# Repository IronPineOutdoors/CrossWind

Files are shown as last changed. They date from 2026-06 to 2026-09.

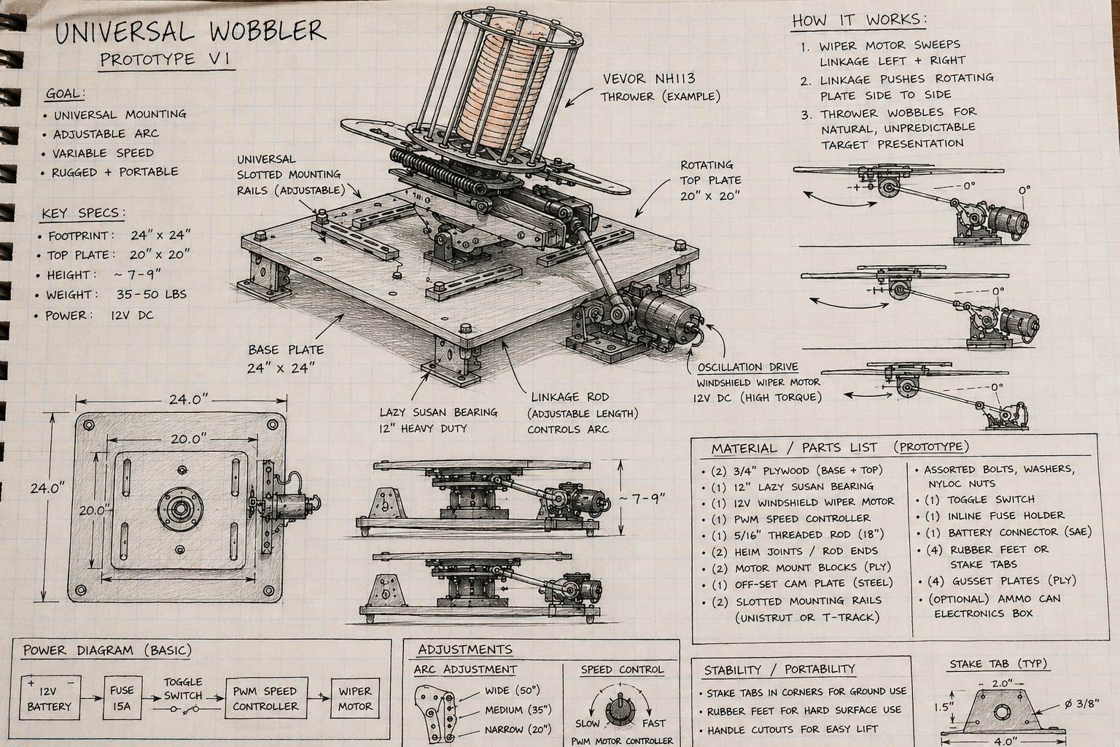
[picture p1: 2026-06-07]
mechanical/sketches/hand_drawn_concept_sketch_photo_style.png

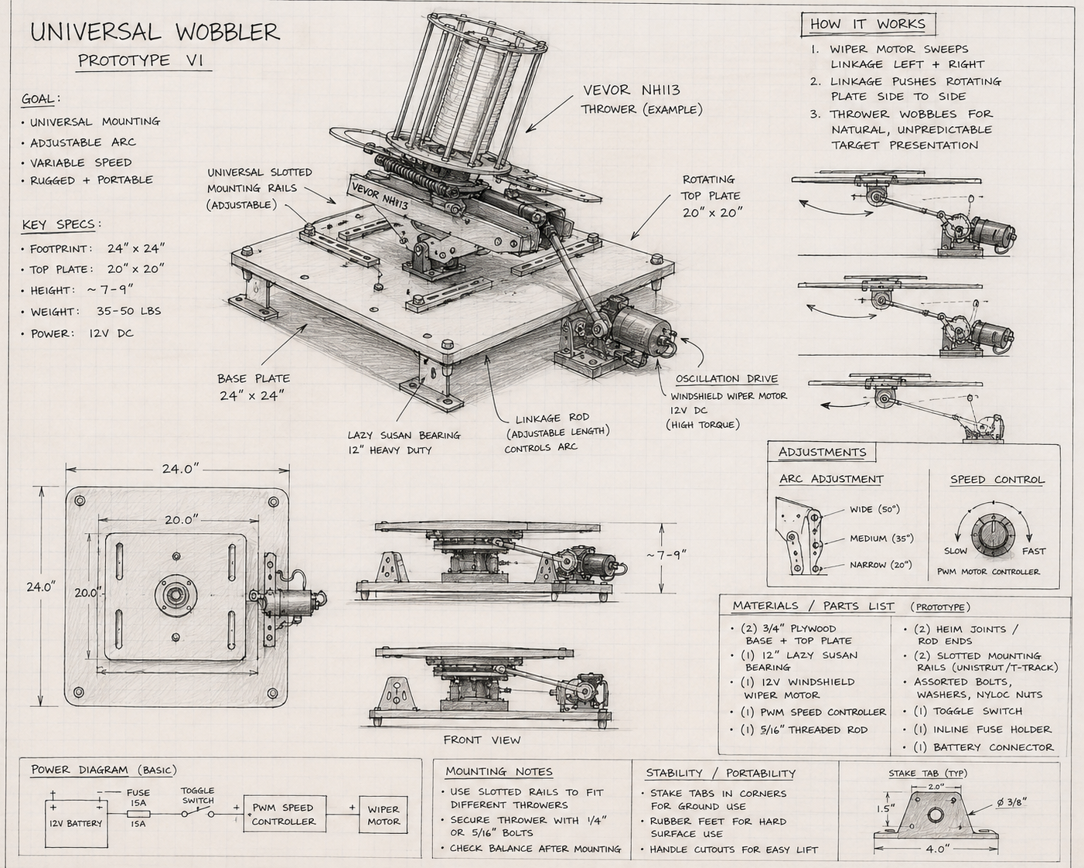
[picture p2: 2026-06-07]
mechanical/sketches/hand_drawn_concept_sketch.png

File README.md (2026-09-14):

# Crosswind

Crosswind is an Iron Pine Outdoors prototype for programmable target presentation: a universal wobbler base that can add controlled yaw, and later pitch, to automatic clay throwers.

Phase 1 is a single-axis yaw/sweep prototype. It uses a rotating thrower deck on a lazy susan bearing, a reversing wiper-motor linkage, a BTS7960 / IBT-2 motor driver, and two YL-99 roller limit modules that define the normal left/right travel boundaries and provide fault protection.

Phase 2 is planned as a dual-axis yaw + pitch system with programmable presentation modes.

ESP32 source identifies as `v1.12.0-rc.1`. Earlier Alpha bench results passed bounded motion and fault checks; the later motor-direction correction still needs physical verification. See [current status](docs/STATUS.md) for evidence and remaining integration work. The hardware below describes the Alpha design, not a completed assembly checklist.

## Current Phase

Phase 1: single-axis sweep prototype.

The first mechanical fitment target is a VEVOR NH113 thrower, but the base, rails, and mounting approach should remain adjustable so Crosswind can support other automatic throwers later.

## Phase 1 Hardware

- ESP32 dev board
- Legacy Arduino Uno/Nano fallback (not Alpha-equivalent)
- BTS7960 / IBT-2 motor driver
- 12V Mitsubishi Outlander rear wiper motor
- Left and right YL-99 limit switch modules
- Rotary encoder speed control with menu/select button
- Dedicated ARM and FIRE / TEST buttons
- Hosyond 2.42-inch 128x64 SSD1309 I2C OLED status display (ASIN B0G2RFLG1L) with the official five-conductor JST lid harness
- BME280 temperature, humidity, and pressure sensor on the shared I2C bus
- Dry-contact thrower trigger relay
- DIYables common-cathode RGB status LED
- 20V/24V tool battery input
- High-current buck converter for 12V bus
- Fused 5V buck converter for controller/support electronics
- Waterproof electronics box
- 28" x 28" 3/4" plywood base
- 20" x 20" rotating thrower deck
- 12" lazy susan bearing

## Folder Structure

- `firmware/crosswind-esp32/` - PlatformIO ESP32 firmware split into motor, limits, inputs, modes, storage, BLE, environment, display, RGB status LED, trigger, and diagnostics modules.
- `firmware/crosswind-arduino/` - Arduino Uno/Nano fallback firmware.
- `mechanical/` - Phase 1 and Phase 2 mechanical notes, dimensions, fitment, and cut lists.
- `electrical/` - Pinout, power system, fusing, the [five-pin OLED lid-harness standard](electrical/oled-lid-harness.md), the [Deutsch DT 6-pin limit-switch harness standard](electrical/limit-switch-harness.md), and wiring checklist.
- `cad/` - CAD export/drop folders for Phase 1 and Phase 2.
- `testing/` - Bench, motor, sweep, runtime, and field test records.
- `branding/` - Iron Pine Outdoors and Crosswind product identity notes.
- `docs/` - Requirements, build plans, safety notes, changelog, and roadmap.

## Quick Start

1. Read `docs/safety-notes.md`.
2. Review `electrical/pinout.md` before wiring.
3. Build the Phase 1 base from `mechanical/phase-1/dimensions.md` and `mechanical/phase-1/cut-list.md`.
4. Flash the ESP32 firmware from `firmware/crosswind-esp32/`.
5. Run `testing/bench-test-checklist.md` with the thrower removed.
6. Mount the thrower only after switch, motor, and fault behavior are verified.

## Safety Warning

Crosswind moves heavy equipment with a 12V motor. Keep hands clear of linkages, rotating plates, pinch points, and the thrower arm path. Use fuses, a shared ground, strain relief, and a reachable power disconnect. Bench test without the thrower mounted before any live thrower test.

## Project Context

- [Current status](docs/STATUS.md): implemented behavior, physical evidence and open questions.
- [Roadmap](docs/roadmap.md): next engineering milestones.
- [Engineering decisions](docs/DECISIONS.md): durable choices and rationale.
- [Codex working guide](AGENTS.md): repository operating instructions.
- [Documentation index](docs/README.md): requirements, build plans, safety and history.

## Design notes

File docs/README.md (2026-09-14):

# Docs

Start with [CrossWind overview](../README.md), then use:

- [STATUS](STATUS.md): current implementation, test evidence and uncertainty.
- [Roadmap](roadmap.md): future work.
- [DECISIONS](DECISIONS.md): important choices and why.
- [AGENTS](../AGENTS.md): how Codex should work in this repository.
- [Product requirements](product-requirements.md): intended capabilities and constraints.
- [Phase 1 build plan](build-plan-phase-1.md) and [Phase 2 build plan](build-plan-phase-2.md): construction plans, not completion records.
- [Safety notes](safety-notes.md): required precautions.
- [Changelog](changelog.md): historical changes.

Detailed implementation belongs with its subsystem:

- [Pinout](../electrical/pinout.md) and [wiring checklist](../electrical/wiring-checklist.md).
- [OLED lid harness](../electrical/oled-lid-harness.md) and [limit harness](../electrical/limit-switch-harness.md).
- [Wiper linkage](../mechanical/phase-1/linkage-notes.md) and [limit layout](../mechanical/phase-1/limit-switch-layout.md).
- [ESP32 firmware](../firmware/crosswind-esp32/README.md), [CAD](../cad/phase-1/README.md) and [test records](../testing/README.md).

Existing nested electrical/mechanical aliases are retained for compatibility; update the canonical subsystem files rather than duplicating detail here.

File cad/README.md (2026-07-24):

# CAD

Store CAD exports and source files here once the physical prototype dimensions settle.

Keep exported PDFs or STEP files alongside native CAD files so collaborators can view designs without the original CAD tool.

Alpha controller-lid CAD must account for the verified 2.42-inch SSD1309 OLED and its official five-conductor, five-position JST harness. See `phase-1/README.md` and `../electrical/oled-lid-harness.md`; use measurements from installed hardware rather than generic display or JST dimensions.

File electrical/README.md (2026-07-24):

# Electrical

This folder documents Crosswind wiring, power distribution, and safety checks.

Use these notes before powering the controller or motor driver.

The finalized limit-switch cable colors, Deutsch DT 6-pin pinout, diagrams, and assembly procedure are in [limit-switch-harness.md](limit-switch-harness.md).

The official Crosswind Alpha OLED connector pinout, five-conductor lid-harness diagram, BOM, fabrication procedure, and acceptance tests are in [oled-lid-harness.md](oled-lid-harness.md).

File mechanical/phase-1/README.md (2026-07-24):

# Mechanical Phase 1

Phase 1 is a single-axis yaw/sweep base.

Core dimensions:

- 28" x 28" fixed plywood base
- 20" x 20" rotating top plate
- 12" lazy susan bearing
- Off-center crank-driven wiper motor mounted to the stationary base plate
- Linkage to the rear corner or tab of the rotating top plate
- Adjustable safety flags/tabs on the rotating plate
- Left/right roller switches on adjustable stationary brackets

The top plate rides on the lazy susan bearing. The wiper motor should mount to the stationary base plate with its output crank offset from the rotation center; the linkage does not need to attach at the exact center of the rotating top plate. Mount the BTS7960 with its heatsink exposed and ventilated inside the electronics enclosure.

See `limit-switch-layout.md` for the Phase 1 YL-99 safety switch layout.

## Controller Display

The controller enclosure now uses a Hosyond 2.42-inch 128x64 SSD1309 OLED. The logical resolution is unchanged, but the larger physical module may require revisions to the panel opening, mounting-hole locations, standoffs, and display bezel.

The enclosure lid must accommodate the official five-conductor OLED harness and five-position JST connector, including strain relief and a service loop. See [OLED Lid Harness Standard](../../electrical/oled-lid-harness.md).

TODO: measure the actual installed OLED module and update the enclosure/CAD dimensions. Do not infer board or mounting dimensions from the 2.42-inch diagonal specification.

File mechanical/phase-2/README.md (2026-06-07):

# Mechanical Phase 2

Phase 2 adds pitch control to the yaw base.

The likely direction is a tilt cradle or adjustable subframe driven by a 12V linear actuator.

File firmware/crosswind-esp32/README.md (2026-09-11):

# Crosswind ESP32 Firmware

Current release candidate: `v1.12.0-rc.1`. The Alpha bounded-motion behavior has been compiled and bench-validated with the installed motor and both YL-99 endpoints.

This folder contains the Phase 1 ESP32 controller firmware in a PlatformIO project.

Current PlatformIO settings:

- Board: `esp32dev`
- Framework: Arduino
- Upload port: `COM3`
- Monitor port: `COM3`
- Monitor speed: `115200`

The code is split into beginner-readable modules:

- `config.h` - pin assignments, constants, shared enums, and the main controller state.
- `motor.*` - BTS7960 / IBT-2 motor control, safe reversal, soft-start ramping, and stop behavior.
- `limits.*` - left/right roller switch reads and debounce.
- `inputs.*` - ARM/FIRE buttons, rotary encoder speed/menu input, and optional speed potentiometer reads.
- `modes.*` - bounded single-axis sweep/reversal and timed centering, with future hooks for the second axis.
- `storage.*` - Preferences-backed mode, last fault, and last speed storage.
- `ble_control.*` - optional BLE command interface.
- `environment.*` - BME280 temperature, humidity, and pressure support.
- `display.*` - U8g2-driven SSD1309 128x64 OLED status display with I2C diagnostics and recovery.
- `status_led.*` - non-blocking DIYables RGB status LED control.
- `trigger.*` - non-blocking thrower relay pulse control.
- `diagnostics.*` - Serial startup diagnostics and runtime status payloads.

## Phase 1 Behavior

Default mode is `SWEEP`. The motor travels between the left and right limit switches, stops at each end, observes direction-change dead time, and reverses. `RANDOM` and `FLUSH` use the same bounded single-axis movement until the second axis and mode-specific motion are added. `CENTERING` establishes both endpoints, measures end-to-end travel time, returns for half that time, and stops.

`MOTOR_DIRECTION_INVERTED = true` corrects the installed motor's reported reverse
travel: logical RIGHT now drives LPWM, and logical LEFT drives RPWM. Direction
names mean plate travel toward the corresponding physical limit, viewed from one
consistent operator position, not shaft rotation viewed from underneath. Limit
wiring remains Left/Green/GPIO34 and Right/Blue/GPIO35. Startup logs the inversion
setting; output diagnostics continue to name the actual RPWM/LPWM terminals.
Do not also swap motor leads when applying this correction, which would reverse
it again. After flashing, first verify direction with unloaded motion away from
endpoints and accessible power cutoff, then verify each actual endpoint causes
reversal away and releases normally. Physical verification remains required.

The Alpha limit switches are normal travel boundaries as well as safety inputs. A single active limit commands movement away from that end; the switch must release within `LIMIT_DWELL_MS`. Both limits active together, failure to release, or failure to reach an endpoint within `MAX_TRAVEL_TIME_MS` latches a fault and stops the motor. A single active limit at startup is valid and establishes the initial direction away from that endpoint.

The controller permits motor START with one limit active because the mode controller selects the direction away from it. ARM and FIRE remain blocked while either limit is active, and a limit transition while armed returns the controller to SAFE. The powered limit modules provide defined HIGH outputs when released and LOW outputs when pressed; limit monitoring and fault protection are enabled. Stored settings are sanity-checked on boot, and BLE speed commands must be numeric values from `0` to `255`.

An E-stop input path exists as a disabled placeholder with `ESTOP_PIN = -1`. Assigning that pin in `config.h` enables a pulled-to-ground emergency stop input that latches `FAULT: ESTOP`. BLE command writes are rate-limited by `BLE_COMMAND_MIN_INTERVAL_MS`.

Motor session timeout and motor overcurrent fault hooks exist but are disabled by default. They require configuring `ENABLE_MOTOR_SESSION_TIMEOUT` or `ENABLE_MOTOR_OVERCURRENT_FAULT` plus the related timeout/current-sense constants in `config.h`.

The Alpha bench controller uses the rotary encoder for speed and local menu control, a dedicated ARM button on GPIO16, and a dedicated FIRE / TEST button on GPIO17. Press the encoder to open the menu, rotate to navigate, and press to select. The menu contains Motor, Mode, Environment, Diagnostics, and About pages. Motor speed has an explicit edit mode; direction and operating-mode changes require the motor to be stopped. Live environment, limit, fault, and relay information is available from the read-only status pages. Select `< Back` to return or `Exit` to close the menu. Any latched fault closes the menu so safety status takes priority. Menu motor control uses the same enabled fault, limit, E-stop, and temperature protections as BLE. The relay can only fire when `systemArmed` is true and no fault is active. The encoder button never triggers the relay.

On boot the system always starts `SAFE` / unarmed and the relay is initialized off. Pressing ARM toggles `ARM ON` / `ARM OFF` in Serial and updates the OLED. Pressing FIRE while safe prints `FIRE BLOCKED - NOT ARMED`; pressing FIRE while armed pulses the relay using the existing non-blocking trigger timing.

The verified Hosyond 2.42-inch 128x64 SSD1309 OLED uses U8g2 and the official five-conductor JST lid harness: GND, 3.3 V, GPIO21 SDA, GPIO22 SCL, and GPIO5 RESET. It retains the existing home-screen layout: motor speed percentage, `SAFE`, `ARMED`, `FAULT`, `WARNING`, or `FIRING`, relay `ON`/`OFF`, and `Limit: OK`, `ACTIVE`, `FAULT: LIMIT`, or `FAULT: BOTH`. At startup it briefly shows an animated Crosswind rotor, moving wind streaks, and a system-start progress bar before transitioning to the home screen. The RGB status LED mirrors the same safety state with green ready, blue armed, red fault, yellow warning/hot, and a white/purple firing flash.

## Build

Install PlatformIO, then run:

```sh
pio run
```

Upload with:

```sh
pio run --target upload
```

GitHub Actions also builds this PlatformIO project on pushes and pull requests that touch `firmware/crosswind-esp32/`.

## BLE Commands

- `START`
- `STOP`
- `MODE=SWEEP`
- `MODE=RANDOM`
- `MODE=FLUSH`
- `MODE=CENTERING`
- `SPEED=0-255`
- `STATUS`
- `CLEAR_FAULT`
- `TRIGGER`
- `FIRE`
- `LAUNCH`

Trigger commands and the FIRE / TEST button pulse the thrower relay only when the system is armed. They are ignored while faulted. The relay pulse remains non-blocking and uses `TRIGGER_PULSE_MS`.

Limit faults can be cleared from BLE with `CLEAR_FAULT`, or locally with the ARM/encoder button, only after both limit switches read clear.

Modes accepted by BLE are `SWEEP`, `RANDOM`, `FLUSH`, and `CENTERING`. `SWEEP`, `RANDOM`, and `FLUSH` currently share bounded end-to-end movement. `CENTERING` measures a complete traverse and returns halfway before stopping. Automatic triggering remains disabled unless `ENABLE_AUTOMATIC_TRIGGER` is intentionally enabled and safety-tested.

## Current Alpha Pinout

| Function | ESP32 GPIO |
| --- | ---: |
| BTS7960 RPWM | 18 |
| BTS7960 LPWM | 19 |
| BTS7960 R_EN | 23 |
| BTS7960 L_EN | 13 |
| Thrower relay input | 14 |
| ARM button | 16 |
| FIRE / TEST button | 17 |
| Rotary encoder CLK | 32 |
| Rotary encoder DT | 33 |
| Rotary encoder SW | 25 |
| Left limit | 34 |
| Right limit | 35 |
| OLED SDA | 21 |
| OLED SCL | 22 |
| OLED RES | 5 |
| BME280 SDA | 21 |
| BME280 SCL | 22 |
| RGB LED red | 27 |
| RGB LED green | 12 |
| RGB LED blue | 4 |
| Potentiometer placeholder | 39 |
| E-stop placeholder | disabled |
| Motor current sense placeholder | disabled |

The DIYables RGB LED module is common cathode with built-in resistors: connect module `GND` to common ground, `R` to GPIO27, `G` to GPIO12, and `B` to GPIO4. GPIO12 is a boot strapping pin on many ESP32 boards. Keep it for the Alpha wiring above; GPIO5 is reserved for OLED reset and is not available as an RGB fallback.

The electrical source of truth for display connector numbering, harness fabrication, and acceptance testing is [OLED Lid Harness Standard](../../electrical/oled-lid-harness.md).

## Environmental Sensor

Alpha firmware reads a BME280 on the existing OLED I2C bus at GPIO21/GPIO22 no faster than once every 2 seconds by default. It tries address `0x76` first and then `0x77`, stores the last valid temperature, humidity, and pressure reading, and reports `ENV ERR` if a read fails. `HOT` appears at `TEMP_WARNING_F`; `TEMP FAULT` stops the motor when `ENABLE_TEMP_FAULTS` is true and temperature reaches `TEMP_FAULT_F`. The Serial/BLE status payload includes `pressureHpa`.

## Quick Test Checklist

See `firmware-test-checklist.md` for a fuller bench checklist and `fault-matrix.md` for fault behavior.

1. Upload firmware with PlatformIO.
2. Confirm Serial reports the I2C scan and SSD1309 address, then confirm the OLED startup test transitions to the home screen.
3. Confirm encoder rotation changes motor speed.
4. Confirm ARM toggles between `SAFE` and `ARMED`.
5. Confirm FIRE is blocked while `SAFE`.
6. Confirm FIRE activates the relay only while `ARMED`.
7. Confirm relay `COM`/`NO` act as dry-contact continuity only.
8. Confirm left/right limits show inactive and active correctly in Serial/OLED setup view.
9. Confirm motor PWM changes speed on the bench before connecting linkage.
10. Confirm a normal endpoint reverses motion, while both limits, a stuck limit, travel timeout, or temperature fault stops motor output and blocks triggering.

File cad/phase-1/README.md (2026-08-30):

# CAD Phase 1

Use this folder for the yaw base, top plate, switch brackets, motor mount, and electronics box layout.

Printable adjustable YL-99 switch holders are in [`limit-switch-holder`](limit-switch-holder/README.md).
Matching printable striker flags are in [`limit-switch-flag`](limit-switch-flag/README.md).

## Controller Lid

The official Alpha controller lid uses the Hosyond 2.42-inch 128x64 SSD1309 OLED and its five-conductor JST harness: GND, 3.3 V, SDA, SCL, and GPIO5 RESET. Future enclosure and wiring-layout CAD must reserve routing, bend clearance, strain relief, and service-loop space for all five conductors and the five-position connector.

The current measured side-panel layout is recorded in [side-panel-layout.md](side-panel-layout.md). The OLED module and primary control locations are measured; dimensions explicitly marked for verification must not be treated as fabrication-ready.

A provisional printable fit-check panel, including four corner M3 mounting holes, is in [`side-panel`](side-panel/README.md).

The matching provisional 30-degree open-back body is in [`control-pod`](control-pod/README.md). A wide bolt-through foot intended to be printed four times is in [`base-foot`](base-foot/README.md).

TODO: measure the JST housing, visible OLED window, standoffs, bezel overlap, cable bend radius, service loop, RGB LED lens/body/PCB, and BME280 board envelope before producing a final dimensional drawing. Do not infer missing dimensions from a generic part name.

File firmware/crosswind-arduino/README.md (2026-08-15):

# Crosswind Arduino AVR Firmware

This folder contains the Arduino Uno/Nano Phase 1 fallback firmware.

Open `Crosswind_Controller/Crosswind_Controller.ino` in the Arduino IDE, select an Uno or Nano board, and upload.

The AVR firmware is a legacy fallback and does not yet mirror the hardware-validated `v1.12.0-rc.1` ESP32 bounded-motion state machine:

- Default mode is `SWEEP`.
- The BTS7960 outputs are handled so both directions are never energized at once.
- Direction changes zero both PWM channels before reversing.
- Limit switches default to normally closed wiring with configurable active state.
- EEPROM stores only mode, last fault, and last speed.

Do not use this fallback for the current Alpha release candidate without separately reviewing and porting endpoint reversal, stuck-limit timeout, travel timeout, and timed centering. The ESP32 firmware is the validated controller for Alpha.

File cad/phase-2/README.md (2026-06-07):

# CAD Phase 2

Use this folder for pitch cradle, actuator mounts, and dual-axis packaging work.

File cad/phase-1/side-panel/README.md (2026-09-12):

# Alpha Side Panel Print

`crosswind_alpha_side_panel.stl` is a provisional, flat-print prototype for checking the OLED and control layout. Print it flat on the bed; supports are not required.

## Current geometry

- Panel: 150 x 100 x 3 mm
- Four panel mounting holes: 3.2 mm diameter (M3 clearance), centers 5 mm from each corner
- OLED visible opening: 57 x 28 mm, shifted 2.75 mm upward from the PCB center
- Four OLED PCB holes: 3.2 mm diameter; horizontal span includes the measured fit correction (left pair 1 mm outward and right pair 1 mm outward)
- ARM and FIRE openings: 16.5 mm diameter, 70 mm center-to-center
- Recessed `ARM` and `FIRE` labels above their respective buttons
- Encoder opening: 8 mm diameter for the threaded bushing, with recessed `SPEED` and `-` / `+` direction markings
- RGB LED opening: provisional 5.2 mm diameter, lowered 11 mm below the OLED for vertical PCB clearance
- Paired 10 mm-tall, 3 mm-thick rear anti-rotation rails around the encoder and RGB LED modules
- Upper-right recessed wordmark: `CROSSWIND` / `BY IRON PINE OUTDOORS`, 0.6 mm deep

The encoder rails provisionally fit an 18 mm-wide PCB and the LED rails a 15 mm-wide PCB, each with 0.4 mm total clearance. Fit-print photos showed that the original 3 mm rails ended below both elevated PCBs; the revised rails rise 10 mm from the rear panel surface and are 3 mm thick so they reach the board edges. They resist rotation but do not replace the components' panel nuts or other retention hardware. The STL is oriented with the exterior/engraved face at Z=0 and the rear rails rising upward, so its default orientation prints without supports. The complete part is mirrored for face-down printing: lettering appears reversed from the tab side in the slicer and reads normally on the finished exterior. Keep the rail contact surfaces clear of solder joints and wiring.

The panel size, OLED window placement, button vertical datum, LED diameter, module widths, and interpretation of the reported OLED mounting-hole spans are provisional. Use this print as a fit coupon/prototype, not as the final weather-sealed panel.

The BME280 mounting tab is intentionally omitted until its PCB envelope, hole coordinates, connector orientation, airflow clearance, and desired location are measured. Those details determine whether the tab belongs on the rear face or panel edge.

A master-power toggle location is not cut yet. Record its panel-bushing or rectangular cutout dimensions, anti-rotation feature, rear body envelope, terminal clearance, and DC voltage/current rating before adding it to the printable panel.

The engraved lockup uses a dependency-free block alphabet sized for FDM printing. For the cleanest lettering, print the exterior face upward at 0.2 mm layers or finer. A contrasting paint fill can be wiped into the recess after printing.

## Regeneration

Install the generator dependency and run:

```powershell
python -m pip install manifold3d
python .\generate_stl.py
```

Edit the constants at the top of `generate_stl.py` when measured dimensions replace the provisional assumptions.

## OLED window fit correction ? 2026-09-12

The installed photo showed the top text clipped and an extra gap below the OLED,
measured by the user at approximately 2.7-2.75 mm. The viewing opening moves
2.75 mm toward the panel top without changing its 57 x 28 mm size. All OLED and
panel mounting holes, control cutouts, and rear rails retain their positions.
The window now spans Y=52.25 to 80.25 mm from the panel bottom (previously
49.5 to 77.5 mm). Reprint the faceplate and check that the top line and bottom
pixel row are visible; this approximate fit correction still needs physical
verification. The existing pod and OLED mounting pattern are reused.

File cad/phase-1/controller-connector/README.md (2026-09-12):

# Controller connector: measured housings and fit gauges

User's existing Alpha controller harness has two six-position joined connections
and one four-position joined connection, each using a middle pin header. Thirteen
positions are used and three reserved. Preserve the existing wire assignments;
this is not a new IPC-101 pinout or a change to its separate STOP interface.

Kit: ELEAD B0G2L3LGWD, marketed as XH-style/Dupont assortment. Do not infer genuine
JST dimensional compatibility or wire-to-wire contact engagement from the title.

## Measurements received 2026-09-11

| Feature | mm | Evidence / interpretation |
| --- | ---: | --- |
| Six-position housing width | 15.97 | Explicitly confirmed by user, photo 184505 |
| Housing depth | 7.91 | Photo 185052; interpreted as mating-axis body depth |
| Six-position housing thickness | 3.98 | Photo 185114 |
| Header feature | 5.53 | Photo 185130; not used as assembled-pair length |
| Four-position housing width | 10.65 | Photo 185203 |
| Four-position housing thickness | 3.85 | Photo 185220 |
| Lip feature | 0.77 | Photo 185248; precise contact faces not established, not used yet |
| Rib inset from each housing end | 2.51 | User confirmed nearest edge; both connector sizes, wire side |
| Rib width | 0.71 | User confirmed; two ribs per housing |
| Maximum hooked-tip width | 1.28 | User confirmed 2026-09-12 after all three gauges caught |
| Rib projection from flat body | 0.79 | User confirmed after first fit print |

The original loose middle-header arrangement below is historical. The selected
IPC-101 carrier now uses matching PCB headers; see the confirmed mating update
at the end of this document. These gauges establish cable-body clearance only.

## Revised print: hooked-rib clearance (2026-09-12)

The first rectangular apertures caught on the two underside ribs. Regenerated
STLs now include two through-notches per opening, on the edge away from the
raised identification dots. Orient the connector ribs toward those notches.
The filenames replace the original rectangular gauges; reload the revised STL
and slice again rather than reusing the previous print job.

All three previous gauges failed to align in the physical fit check. The new
close-up shows angled ribs with wider hooked tips; the user measured the maximum
tip width as 1.28 mm, versus the 0.71 mm shaft used previously.

Rib locations retain the measured 2.51 mm shaft inset. Because the lateral tip
offset and rib angle are unmeasured, this diagnostic revision allows the extra
0.57 mm on BOTH sides of each shaft, making a 1.85 mm swept envelope before
clearance. This is a conservative test allowance, not a measured hook profile.
Notch widths are now 2.05, 2.25, and 2.45 mm for one, two, and three dots.
The same allowance is provisionally used for both housing sizes; verify each.
Each notch still extends 0.79 mm beyond the rectangular aperture edge, preserving
the same per-side clearance at the rib tip as at the flat body. Hook projection
has not been remeasured. The main rectangular openings are unchanged.
Reload and reslice the regenerated STLs; dot counts and filenames are unchanged.

Print `Connector_Fit_All_Three_PRINT.stl` on the A1 in PETG, 0.4 mm nozzle,
0.2 mm layers, four walls, solid fill; flat as exported, no supports. Individual
STLs are provided if only one clearance needs repeating. The three gauges are
38 x 16 x 2 mm plus raised identification dots; the combined print is 38 x 58 mm.

Each gauge has a wide six-position opening and a narrower four-position opening.
The added clearance is TOTAL, so 0.4 mm means 0.2 mm per side for a centered part.

| Raised dots | Total added clearance | Six-position opening | Four-position opening |
| ---: | ---: | --- | --- |
| 1 | 0.2 mm | 16.17 x 4.18 mm | 10.85 x 4.05 mm |
| 2 | 0.4 mm | 16.37 x 4.38 mm | 11.05 x 4.25 mm |
| 3 | 0.6 mm | 16.57 x 4.58 mm | 11.25 x 4.45 mm |

With power removed, test loose housings by inserting the body gently into its
opening. Do not force a flange/latch through an opening intended for the body;
note whether it is the body or an external ridge that stops insertion. Remove
first-layer burrs before judging fit. Report the smallest gauge that slides
without force for EACH connector size. These are dimensional coupons, not
electrical housings, clamps or strain relief.

## Confirmed fit selections (2026-09-12)

Use these separate clearances for subsequent carrier design, retaining the
revised hooked-rib relief geometry:

| Housing | Selected gauge | Total clearance | Main opening | Rib-notch width |
| --- | --- | ---: | --- | ---: |
| Six-position | 2-dot | 0.4 mm | 16.37 x 4.38 mm | 2.25 mm |
| Four-position | 3-dot | 0.6 mm | 11.25 x 4.45 mm | 2.45 mm |

User reported the revised 1-dot was still close on the six-position housing and
the four-position housing did not pass through. The revised 2-dot fit the
six-position housing well, but the four-position housing required force.
Possible hook damage on that forced sample was not confirmed. The user then
checked a fresh four-position housing directly in the revised 3-dot and confirmed
that they liked its fit; the four-position selection is based on that fresh
sample. Existing comparison-gauge STLs remain unchanged.

These results establish aperture fit only; joined-pair engagement and carrier
retention remain to be established.

## Remaining design inputs

- Fixed PCB-header dimensions, tail geometry, pin spacing/offset and fully mated
  envelope for both sizes; the loose middle-header concept is superseded.
- Final retention must leave the metal contacts fully engaged without pushing
  pins backward or relying on the wires for structural support.
- USB service port remains a separate pending task: ESP socket type, mounting
  location and chosen extension cable geometry have not yet been confirmed.

`generate_fit_gauges.py` verifies clear apertures, manifold status, watertightness,
consistent winding, positive volume and the expected number of separate solids.
Physical dimensions and connector retention require printed fit verification.

## IPC-101 development direction (2026-09-12)

The user selected IPC-101 for Alpha and future IPC-100. The new carrier plan uses
one accepted six-position OLED opening and one accepted four-position controls
opening, with STOP separate. The earlier 6+6+4 description records the existing
Alpha harness, not the new panel allocation. See the
[IPC-101 adapter specification](../../../electrical/ipc101-adapter-plan.md) for
circuit assignments, firmware gaps, GPIO savings and remaining mechanical inputs.

## Confirmed PCB-header mating (2026-09-12)

User confirmed both cable housings connect to the kit's matching shrouded PCB
headers and hold via their hooks (assembled-pair photo 20260912_100515.jpg).
Develop the fixed side around these headers on a supported adapter PCB. Preserve
hook engagement and release access. Existing gauge fits remain cable-clearance
references, not dimensions for mounting the larger header bodies. Electrical
continuity and header/PCB dimensions remain unverified.

## PCB-header test prints

New fixed-header body and solder-tail coupons are ready in
`PCB_Header_All_Tests_PRINT.stl`. Follow
[PCB header test instructions](PCB_Header_Test_Instructions.md); these use
provisional photo-derived shroud sizes and do not replace the accepted cable
housing gauges.

### Header fit feedback and refinement

On 2026-09-12 the user corrected the solder-tail selection to TWO dots (1.1 mm
square holes); ONE dot (0.9 mm) was too tight. Original one-dot
body openings were closest but still slightly oversized. New body-only tests:
`PCB_Header_Refine_All_PRINT.stl`, with a raised bar distinguishing this series.
See the refinement table in the test instructions. Original files are preserved.

### Four-pin outer-edge adjustment

Refinement three-dot was preferred, with the four-pin outer side still slightly
snug and causing a subtle angle. `PCB_Header_Outer_Relief_All_PRINT.stl` tests
0.2 / 0.4 mm relief at only the four-pin outboard short edge. Two raised bars
identify this series; see the test instructions. Six-pin remains 18 x 7 mm.

## Fit clarification: raised identification dots (2026-09-12)

User subsequently attributed the apparent four-pin tilt to the raised coupon
dots preventing the plates from sitting flush together, and believes the fit is
OK. Retain refinement THREE-dot body openings: six-pin 18.0 x 7.0 mm and four-pin
13.0 x 7.0 mm. Retain original TWO-dot tail holes: 1.1 mm square at provisional
2.50 mm pitch. The outer-edge-relief coupons are superseded diagnostic options;
do not carry their enlargement into the carrier. Final mating/support surfaces
must be flat, with identification outside those surfaces. Integrated header
seating and mating still need an assembly fit check.

## Next assembled fit print

`PCB_Header_Assembly_All_PRINT.stl` contains a flat guide, sliding pin plate and
open stand. Follow [assembly instructions](PCB_Header_Assembly_Instructions.md).
This combines the accepted body and pin fits without raised dots interfering
with seating. It is a hand-held alignment test, not a retained final connector.

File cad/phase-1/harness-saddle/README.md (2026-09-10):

# Harness saddle for 13.8 mm automotive loom

First-fit prototype for tubing measured at 13.8 mm outside diameter. Install over
an existing harness with the open side against the wooden mounting surface.

- Installed envelope: 42 x 18 x 17 mm.
- Smooth channel: 14.2 mm wide, 13.8 mm high above the mounting surface.
- Arch wall: 3.2 mm; mounting ears: 4 mm thick.
- Two 4.6 mm clearance holes, 30 mm center to center, for #6 or #8 screws.
- Flat screw seats accept pan heads; small flat washers can spread the load.
  Use washers no larger than 9 mm OD to retain clearance to the arch.

## Bambu A1 printing

Open `Crosswind_Harness_Saddle_13.8mm_PRINT.stl` in Bambu Studio and select your
A1 and actual filament profile. The STL is already resting on its flat end face:
the print is 18 mm tall and the arch lies in the layer plane. Do not auto-orient
it onto the mounting ears. Use PETG, a 0.4 mm nozzle, 0.2 mm layers, five walls,
five top/bottom layers, and 35% gyroid infill. Supports are not intended; the
horizontal 4.6 mm screw bores have short bridges. Deburr/check screw passage.
Use a 3 mm outer brim if adhesion requires it. Print one for fit before making more.

## Mounting and grip

For 3/4-inch plywood use two #6 or #8 x 3/4-inch pan-head WOOD screws.
Machine screws require nuts or threaded inserts. The 4 mm ears leave at most
15.05 mm of screw penetration before adding washers, below 19.05 mm plywood
thickness. Verify the actual wood thickness and bearing clearance first.
Pilot drill to suit the wood and screw root diameter; limit drill depth.
Snug the ears against the wood without crushing the print or tubing.

This is a loom hold-down, with strain relief dependent on actual friction and
loom stiffness. Corrugation pitch and groove diameter were not supplied, so
there are no groove-locking teeth. The channel has lateral clearance and nominal
contact at its crown; it does not guarantee axial retention. With power off,
check whether the loom slides under the expected pull. A thin rubber strip may
improve grip if it fits without forcing the ears down or crushing the loom.
Wires may slide independently inside split loom: retain the harness separately
where connector strain relief is required. Leave a service loop at moving joints.

`generate_stl.py` recreates the STL and preview and checks one connected,
watertight, consistently wound solid, positive volume, and bounding dimensions.
Mesh checks do not establish physical fit or pull strength.

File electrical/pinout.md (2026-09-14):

# Pinout

## ESP32 Pins

| Function | ESP32 Pin | Notes |
| --- | --- | --- |
| BTS7960 RPWM | GPIO18 | RPWM terminal; logical LEFT with current inverted mapping |
| BTS7960 LPWM | GPIO19 | LPWM terminal; logical RIGHT with current inverted mapping |
| BTS7960 R_EN | GPIO23 | Right enable |
| BTS7960 L_EN | GPIO13 | Left enable |
| SSD1309 OLED SDA | GPIO21 | Shared I2C bus |
| SSD1309 OLED SCL | GPIO22 | Shared I2C bus |
| SSD1309 OLED RES | GPIO5 | Active-LOW hardware reset for five-pin module |
| BME280 SDA | GPIO21 | Optional environment sensor on shared I2C bus |
| BME280 SCL | GPIO22 | Optional environment sensor on shared I2C bus |
| Left limit | GPIO34 | Green, DT pin 1; powered module OUT, active LOW; module onboard pull-up |
| Right limit | GPIO35 | Blue, DT pin 2; powered module OUT, active LOW; module onboard pull-up |
| ARM button | GPIO16 | Button to GND, `INPUT_PULLUP`, pressed LOW |
| FIRE / TEST button | GPIO17 | Button to GND, `INPUT_PULLUP`, pressed LOW |
| Speed potentiometer | GPIO39 | 0-3.3V analog input |
| Rotary encoder CLK | GPIO32 | Active speed input in current ESP32 build |
| Rotary encoder DT | GPIO33 | Active speed input in current ESP32 build |
| Rotary encoder SW | GPIO25 | Menu/select button |
| Thrower trigger relay | GPIO14 | Relay input only; relay contacts are dry contact across pedal wires |
| RGB LED red | GPIO27 | DIYables common cathode RGB module R input, PWM |
| RGB LED green | GPIO12 | DIYables common cathode RGB module G input, PWM |
| RGB LED blue | GPIO4 | DIYables common cathode RGB module B input, PWM |

## BTS7960 Pins

- `B+` and `B-` connect to the fused 12V bus from the high-current buck converter.
- `M+` and `M-` connect to the wiper motor.
- `RPWM`, `LPWM`, `R_EN`, and `L_EN` connect to the ESP32 pins above.
- ESP32 ground, BTS7960 logic ground, buck ground, and battery negative must be common.

## Limit Switches

Use the [finalized limit-switch harness standard](limit-switch-harness.md): Green / DT pin 1 is Left OUT, Blue / pin 2 is Right OUT, White / pin 3 is Lower OUT, Yellow / pin 4 is Upper OUT, Black / pin 5 is shared ground, and Red / pin 6 is regulated 3.3 V. The powered modules output HIGH normally and short OUT to ground when pressed, so active is LOW.

During Alpha, Green, Blue, Black, and Red are connected. White and Yellow remain terminated but unused. GPIO34/GPIO35 do not support internal pull-ups, so Alpha relies on the powered modules' onboard pull-ups. A broken or disconnected OUT wire leaves the input undefined and is not automatically detected. These switches command normal reversal and provide safety input, but separate physical hard stops remain required.

## RGB Status LED

The DIYables RGB LED module is common cathode with built-in resistors. Connect module `GND` to common ground, `R` to GPIO27, `G` to GPIO12, and `B` to GPIO4. Because common cathode colors turn on when driven HIGH, PWM values above 0 illuminate the color and PWM 0 turns it off.

GPIO12 can affect boot mode on some ESP32 boards if externally pulled at reset. Keep GPIO12 for the current Alpha wiring unless it causes boot or upload issues. GPIO5 is now reserved for OLED reset and must not be used as an RGB fallback.

## Buttons

ARM and FIRE / TEST buttons connect from their GPIO pin to ground and use internal pullups. Pressed reads LOW.

## Potentiometer

Use a potentiometer wired between 3.3V and GND, with the wiper to GPIO39. Do not connect 5V to an ESP32 analog pin. The current ESP32 build is configured for the rotary encoder instead; switch `SPEED_INPUT_TYPE` in firmware if using the potentiometer.

## Rotary Encoder

Wire encoder `CLK` to GPIO32, `DT` to GPIO33, `SW` to GPIO25, `+`/`VCC` to ESP32 `3V3`, and `GND` to common ground. The firmware uses internal pullups, so the encoder outputs and switch should pull the pins to ground when active.

The encoder switch opens/selects the local Motor, Mode, Environment, Diagnostics, and About menus. It never triggers the relay.

The Hosyond 2.42-inch 128x64 SSD1309 OLED shares the I2C bus on GPIO21/GPIO22. Connect OLED `VCC` to ESP32 `3V3`, `GND` to system ground, `SDA` to GPIO21, `SCL` to GPIO22, and `RES` to GPIO5. Crosswind continues to supply 3.3 V even though the module listing indicates 3.3-5 V compatibility. Firmware pulses the active-LOW reset before scanning the bus, uses centralized address `0x3C`, and retains `0x3D` as a diagnostic fallback.

These five signals must run through the official five-position JST lid connector. Use the numbered pinout, diagram, BOM, and fabrication procedure in [OLED Lid Harness Standard](oled-lid-harness.md).

## Environmental Sensor

Crosswind Alpha uses a BME280 on the OLED I2C bus for temperature, humidity, and pressure. Wire BME280 `VCC` to ESP32 `3V3`, `GND` to common ground, `SDA` to GPIO21, and `SCL` to GPIO22. The firmware tries address `0x76`, then `0x77`.

Mount the sensor inside the enclosure where air can circulate. Keep it away from the BTS7960 heat sink, motor driver body, and direct contact with the case wall so readings are not dominated by a local hot surface.

## Thrower Trigger Relay

Use an opto-isolated relay module or equivalent dry-contact relay output. ESP32 GPIO14 drives the relay input. The relay `COM` and `NO` contacts wire in parallel with the VEVOR NH113 factory foot pedal wires after confirming the pedal pair with a continuity test.

The ESP32 must never send voltage into the thrower pedal circuit. Use the relay contacts as a switch only.

## Future Battery Sense

Reserved placeholders exist in firmware for:

- Battery voltage divider input, currently disabled with `BATTERY_VOLTAGE_PIN = -1`
- Motor current sense input, currently disabled with `MOTOR_CURRENT_SENSE_PIN = -1`
- Pitch actuator output

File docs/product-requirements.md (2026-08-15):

# Product Requirements

## Phase 1 Requirements

- Provide a single-axis yaw/sweep base for automatic clay throwers.
- Support the VEVOR NH113 as the first fitment target.
- Keep the thrower mounting approach adjustable for universal compatibility.
- Use two YL-99 roller limit modules as normal left/right travel boundaries and safety inputs. They are not physical hard stops and must actuate before separate mechanical stops.
- Run from a 20V/24V tool battery stepped down to a fused 12V bus and fused 5V electronics bus.
- Use an ESP32 controller with rotary speed control, ARM/FIRE safety controls, OLED status, and dry-contact relay triggering.
- Default to `SWEEP` mode.
- Stop and reverse after the limit in the direction of travel activates. Permit motion only away from a single active limit; fault if both limits activate, a departed limit fails to release, or the opposite endpoint is not reached before the travel timeout.
- Provide timed `CENTERING` by measuring one end-to-end traverse and returning for half the measured travel time.
- Work fully without BLE connected.

## Phase 2 Requirements

- Add pitch control using a tilt cradle or equivalent thrower support frame.
- Add pitch limit switches or position feedback.
- Expand ESP32 control to coordinate yaw and pitch.
- Preserve safe fault behavior for each motion axis.
- Explore programmable target presentation patterns.
- Account for higher battery draw from a second actuator.

## Future Production Requirements

- Weather-resistant enclosure and connectors.
- Serviceable wiring harness.
- Clearly labeled controls and fuse access.
- Stable mounting rails for multiple thrower footprints.
- Repeatable calibration procedure.
- Battery voltage monitoring.
- OLED or app-based status display.
- Field test logs for durability, runtime, and transport vibration.

## Non-Goals

- Phase 1 does not need pitch.
- Phase 1 does not need a mobile app to operate.
- Phase 1 does not need production-grade molded parts.
- Phase 1 does not need a universal rail kit finalized before basic motion is proven.

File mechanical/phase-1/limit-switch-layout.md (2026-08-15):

# Limit Switch Layout

Crosswind Alpha uses two YL-99 roller limit modules as normal reversal boundaries and safety inputs.

- Mount the YL-99 modules on adjustable brackets attached to the stationary 28" x 28" base plate.
- Mount adjustable flags or tabs on the rotating top plate.
- Place flags near the rotating plate edge or a rear tab where they can be adjusted without disturbing the crank linkage.
- The flags should contact the YL-99 roller arms lightly and repeatably.
- The switch roller arms should not carry mechanism loads.
- The switches command firmware reversal but are not load-bearing physical hard stops.
- Add separate rubber or metal stops just beyond the switch actuation points for independent overtravel protection.
- Route switch wiring so it cannot touch the lazy susan bearing, linkage, crank arm, or rotating plate.
- Use Green for Left OUT, Blue for Right OUT, Black for shared ground, and Red for regulated 3.3 V in accordance with the [Deutsch DT 6-pin harness standard](../../electrical/limit-switch-harness.md).
- Keep the terminated White and Yellow conductors insulated and secured during Alpha.

Firmware stops and reverses away from the single limit reached in the direction of travel. It latches a fault if both switches activate, the departed switch fails to release within `LIMIT_DWELL_MS`, or the next endpoint is not reached within `MAX_TRAVEL_TIME_MS`.

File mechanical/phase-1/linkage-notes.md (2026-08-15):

# Linkage Notes

Start with conservative linkage geometry and travel. The motor reverses at the YL-99 endpoints, so the linkage must move through the complete bounded range without crossing an over-center lock, binding, or relying on continuous crank rotation.

Mount the wiper motor on the stationary base plate, off-center from the lazy susan bearing. Attach the linkage to a rear corner bracket or tab on the rotating top plate unless testing shows a better leverage point. The linkage does not need to attach at the rotation center.

Watch for:

- Binding near each travel end.
- Linkage collision with the bearing or top plate.
- Safety flag missing the YL-99 roller.
- Linkage reaching a dead-center or over-center condition before either switch actuates.
- Mechanical hard stop contact before the corresponding switch actuates.
- Motor mount flex under load.
- BTS7960 heat sink enclosed without airflow.

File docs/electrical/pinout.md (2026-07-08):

# Pinout

The canonical current ESP32 pinout lives at:

- `../../electrical/pinout.md`

That file is kept outside `docs/` with the rest of the wiring package so pinout, power, trigger, fuse, and checklist notes stay together.

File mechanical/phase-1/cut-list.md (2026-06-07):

# Phase 1 Cut List

## Plywood Cuts

- One 28" x 28" base from 3/4" plywood.
- One 20" x 20" rotating top plate.

## Motor Block

- One temporary motor mounting block sized to the Mitsubishi Outlander rear wiper motor.
- Shim stock or spacer blocks for alignment during linkage tests.

## Temporary Switch Brackets

- Two adjustable brackets for roller limit switches.
- Slots are preferred over fixed holes until sweep angle is proven.

## Optional Stake Tabs

- Four small tabs or corner blocks can be added for ground stakes or tie-downs.

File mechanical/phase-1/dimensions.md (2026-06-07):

# Phase 1 Dimensions

- Base: 28" x 28" x 3/4" plywood.
- Rotating plate: 20" x 20" plywood.
- Bearing: 12" lazy susan bearing centered between base and plate.

## Suggested Layout

- Place the battery near the rear or side to help keep the base planted.
- Place the electronics box where cables can reach motor, switches, and controls without crossing the linkage.
- Mount the wiper motor to the fixed base.
- Keep the linkage below or outside the thrower footprint.
- Leave room for adjustable thrower rails on the top plate.

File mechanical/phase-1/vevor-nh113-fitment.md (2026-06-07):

# VEVOR NH113 Fitment

The VEVOR NH113 is the first test-fit thrower for Crosswind Phase 1.

Use it to validate:

- Top plate size.
- Rail spacing.
- Center of mass.
- Cable clearance.
- Thrower access for loading and adjustments.

Keep rails adjustable so the design remains useful for other automatic throwers.

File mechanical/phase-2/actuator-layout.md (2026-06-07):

# Actuator Layout

Phase 2 actuator planning should account for:

- Stroke length.
- Force rating.
- Mounting angle.
- Limit switch placement.
- Mechanical stops.
- Current draw and fuse sizing.

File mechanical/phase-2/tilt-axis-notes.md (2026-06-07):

# Tilt Axis Notes

The tilt axis should support the thrower without stressing the thrower frame. The pivot should stay stable under recoil, vibration, and uneven ground.

Open questions:

- Pivot height.
- Cradle width.
- Service access.
- Pitch range.
- Transport lock.

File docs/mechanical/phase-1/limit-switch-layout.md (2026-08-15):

# Limit Switch Layout

The canonical Phase 1 YL-99 limit switch layout lives at:

- `../../../mechanical/phase-1/limit-switch-layout.md`

Those notes describe stationary-base switch mounting, rotating-plate flags/tabs, normal firmware reversal, and the requirement for separate physical hard stops.

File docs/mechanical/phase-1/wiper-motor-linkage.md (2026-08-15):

# Wiper Motor Linkage

The canonical Phase 1 wiper motor linkage notes live at:

- `../../../mechanical/phase-1/linkage-notes.md`

Those notes describe the current reversing wiper-motor layout: motor on the stationary base plate, linkage to a rear corner/tab of the rotating top plate, YL-99 endpoint reversal, and independent mechanical overtravel stops.

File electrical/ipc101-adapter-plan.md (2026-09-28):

# IPC-101 panel adapter and connector development

Status: development specification, 2026-09-12. User selected IPC-101 as the panel
for Alpha and future IPC-100. User expects the PCB around September 14-16;
arrival estimate is not independently verified. No harness has been electrically
validated and no IPC-101 firmware support has been installed by this change.

## Architecture

IPC-101 panel -> printed connector carrier -> replaceable equipment adapter
-> Alpha ESP32 now, IPC-100 later.

Use one measured four-position housing for controls (K) and one measured
six-position housing for OLED (D). The previously considered second six-position
connection is unnecessary for these functions and is omitted. These are new
IPC-101 adapter assignments, not a reassignment of the existing Alpha harness.
Keep the original harness intact and label the new assembly IPC101.

STOP uses its own distinctive two-position connector, physically incompatible
with K and D. Neither STOP conductor is logic ground. IPC-101 J3 is an isolated
pass-through, not a keypad input.

## As-built Alpha DT8 enclosure harness (2026-09-28)

The Alpha IPC-101 enclosure harness has now been physically assembled using an
8-position Deutsch-style DT8 connector. The following cavity assignment and
wire colors are the **as-built Alpha harness standard** and supersede the earlier
DT12 direction for this enclosure interface.

| DT8 cavity | Signal | As-built conductor |
| ---: | --- | --- |
| 1 | +3.3 V | 22 AWG Red |
| 2 | Logic GND | 22 AWG Black |
| 3 | SDA / ESP32 GPIO21 | 22 AWG Blue |
| 4 | SCL / ESP32 GPIO22 | 22 AWG Yellow |
| 5 | OLED RESET / ESP32 GPIO5 | 22 AWG Green |
| 6 | STOP_IN | 22 AWG Red with green identification |
| 7 | STOP_RETURN | 22 AWG Black with green identification |
| 8 | RESERVED | Empty |

STOP_RETURN remains electrically separate from logic GND; cavity 7 must not be
bonded to cavity 2. The green identification on the cavity 6/7 conductors marks
the dedicated STOP pair and distinguishes it from the red/black logic power pair.

The installed DT8 housing was measured by the user at 36.7 mm maximum width,
25.4 mm maximum height, and 58.2 mm overall housing length. A 40.0 x 29.0 mm
rounded-rectangle pass-through is being evaluated as prototype fit geometry.
That opening is not fabrication-frozen until a physical coupon test passes.

Before first powered operation, verify point-to-point continuity for cavities
1-7, verify no adjacent-cavity shorts, verify no continuity between cavity 2
(LOGIC GND) and cavity 7 (STOP_RETURN), and verify +3.3 V polarity with the
IPC-101 disconnected.

## Selected mating arrangement (2026-09-12)

User confirmed that both four- and six-position cable housings mate with the
kit's shrouded PCB pin headers and are retained by the previously measured hooks.
Photo 20260912_100515.jpg shows the assembled pairs. Use these matching headers
as the fixed halves, replacing the earlier two-cable-housings/middle-header idea.
This confirms user-observed mechanical mating and hook retention, not electrical
continuity, endurance or environmental qualification.

Mount the headers on a small adapter PCB supported by the printed carrier.
Keep hook engagement and unplugging access clear; the carrier supports the board
and fixed headers and provides cable strain relief. Do not use the tested
cable-housing apertures as header mounting-pocket dimensions.

## Circuit assignment draft

K1-K4 and D1-D6 below are logical cavity labels, not a released crimp-face drawing.
Mark and verify cavity orientation on the actual housings and continuity through
the matching PCB header before releasing a harness drawing; mating faces can mirror.

| Carrier circuit | IPC-101 endpoint | Alpha adapter endpoint | IPC-100 adapter endpoint |
| --- | --- | --- | --- |
| K1 | J1.1 keypad 3.3 V | regulated 3.3 V branch | J10.1 EXPANSION_VCC |
| K2 | J1.2 GND | logic GND | J10.2 GND |
| K3 | J1.3 SDA | GPIO21 SDA | J10.3 SDA |
| K4 | J1.4 SCL | GPIO22 SCL | J10.4 SCL |
| D1 | J4.1 OLED_VCC | regulated 3.3 V branch | J6.1 OLED_VCC |
| D2 | J4.2 OLED_GND | logic GND | J6.2 OLED_GND |
| D3 | J4.3 OLED_SDA | GPIO21 SDA | J6.3 OLED_SDA |
| D4 | J4.4 OLED_SCL | GPIO22 SCL | J6.4 OLED_SCL |
| D5 | J4.5 OLED_RESET | GPIO5 | J6.5 OLED_RESET |
| D6 | no connection | no connection | no connection |
| Separate STOP 1 | J3.1 STOP_IN_RAW | hardware integration pending | J8A STOP_IN_RAW |
| Separate STOP 2 | J3.2 STOP_RETURN | hardware integration pending | J8A STOP_RETURN |

IPC-101 J2 remains the local five-wire connection to the actual OLED module.
Verify module markings and reset continuity; its physical pin order is not
inferred from the carrier circuit order. Use proper mating GH pigtails at J1/J4;
the tested XH-style kit housings do not mate directly with those GH headers.

Keep K and D power, return and bus wires independent throughout the panel harness.
Only the Alpha equipment adapter joins their corresponding buses/rails. The
future IPC-100 adapter routes them to the separate J10 and J6 branches. Never
carry the Alpha branch bridges into that adapter.

Design to the existing IPC-101 interface limits: complete keypad branch <=0.30 m;
complete OLED branch, including J2-to-display wiring, <=0.20 m and 50 pF.
Inspect pull-ups and the 3.3 V supply budget before bench operation; retain the
IPC-100 protected power and pull-up contracts when migrating. Power-off mating.

## Cable-housing clearance references and carrier geometry

- K: 11.25 x 4.45 mm main aperture, 2.45 mm hooked-rib notches (fresh four-pin
  housing accepted in revised three-dot gauge).
- D: 16.37 x 4.38 mm main aperture, 2.25 mm hooked-rib notches (six-pin housing
  accepted in revised two-dot gauge).
- Retain the gauge's rib positions and 0.79 mm notch extension.
- Label K / CONTROLS and D / DISPLAY; use asymmetric carrier assembly features
  to prevent reversing the carrier. Housing orientation still needs verification.
- Design board supports and a removable board retainer around the fixed PCB
  headers; leave room for the cable housings to seat and release their hooks.
- The aperture dimensions above are accepted cable-body clearance references.
  Final access openings must also clear the header shrouds and mating motion.

No final carrier STL or adapter PCB is released yet. Still needed for each
header: plastic body width, thickness and height excluding tails; solder-tail
length and cross-section; first-to-last pin center span; pin-row offset from the
body edges; and the fully mated envelope. Confirm these with calipers rather than
inferring a nominal kit pitch from ruler photos. Retainer/support geometry must
be based on the fixed headers and board, not the superseded loose middle header.

## Alpha firmware work required

Current inputs.cpp reads ARM GPIO16, FIRE GPIO17 and encoder GPIO32/33/25;
there is no TCA8418 driver. Existing Wire/I2C initialization supports OLED/BME280,
but does not interpret IPC-101 key events automatically.

Add an explicit IPC-101 panel mode while retaining the legacy input mode:

1. Probe TCA8418 at 0x34, initialize R0-R6/C0 and poll its debounced event FIFO
   every 10-20 ms on a 100 kHz bus. Verify register programming against TI's
   datasheet and the fabricated Rev C netlist when implementing.
2. Map R0 LEFT, R1 RIGHT, R2 UP, R3 DOWN, R4 SELECT, R5 ARM (called START in
   earlier architecture notes), R6 PULL into the existing application controls.
   Define navigation/speed behavior explicitly in the implementation.
3. Preserve ARM/PULL edge qualification and existing actuator interlocks. Handle
   missing panel, I2C errors, overflow and reconnect without replaying stale
   commands or treating a held button as a fresh press; bench-test these cases.
4. Drive Rev C common-anode RGB through TCA8418 COL6/COL7/COL8. Current Alpha
   status_led.cpp instead uses ESP32 PWM for a common-cathode module. Do not
   assume the same PWM brightness/fade behavior is available through the scanner.
5. Disable legacy GPIO input/output initialization in IPC-101 mode before
   treating those pins as available. No firmware is flashed by this plan.

| Removed Alpha function | GPIOs potentially available after migration |
| --- | --- |
| Individual ARM and FIRE buttons | 16, 17 |
| Rotary encoder, replaced by P504 navigation | 32, 33, 25 |
| External RGB, replaced by IPC-101 RGB | 27, 12, 4 |

Five pins become available with controls migration, eight including RGB.
GPIO21/22 remain I2C; GPIO5 remains OLED reset. GPIO39 is already unused in the
current encoder configuration. Pin reuse remains subject to ESP32 pin constraints.
The current ESTOP_PIN is -1: STOP hardware integration is a separate unfinished
part of the Alpha adapter, not supplied by the I2C migration.

## Compatibility and verification

IPC-100's documented interface already targets IPC-101 at address 0x34 through
J10, OLED through J6 and STOP through J8A. Its driver/population and hardware
acceptance still need verification; the interface contract is not evidence of
completed firmware or a validated physical connection.

On PCB arrival, follow IPC-101's Rev C arrival checklist, verify harness continuity
and supply polarity, then test keys, display and LED with motor/trigger outputs
disconnected. Validate disconnect/reconnect and STOP independently before motion.

Sources: sibling IPC101/docs/interface/IPC100_IPC101_INTERFACE.md;
IPC101/docs/architecture/IPC101_ARCHITECTURE.md;
IPC101/hardware/kicad/README.md (Rev C RGB assignment);
Crosswind firmware/crosswind-esp32/src/{config.h,inputs.cpp,status_led.cpp};
cad/phase-1/controller-connector/README.md (physical fit results).

## Header pin measurements (2026-09-12)

User measured a 1.83 mm clear gap between adjacent pins and a 0.64 mm pin width
in the same direction. Calculated adjacent center spacing is 2.47 mm (1.83 +
0.64). This is a measured estimate, not a released nominal footprint pitch;
the header size measured was not specified. Do not assume it establishes both
header sizes or the other dimension of the pin cross-section.

Confirm the full row span before PCB layout: measure the outside-to-outside span
of the first and last pins. For six pins, pitch = (span - 0.64 mm) / 5, assuming
the measured pin width applies. This reduces sensitivity to a single-gap reading.

User subsequently measured 13.20 mm outside-to-outside across the six-pin row.
Using the 0.64 mm pin width, the first-to-last center span is 12.56 mm and
average pitch is 12.56 / 5 = 2.512 mm. Prefer this full-row estimate over the
earlier 2.47 mm single-gap estimate. Use 2.50 mm as a provisional layout target,
not a confirmed manufacturer specification; verify with a physical footprint
fit before fabrication. Four-pin row span remains unconfirmed.

## PCB-header coupon results (2026-09-12)

User corrected the pin-hole result: TWO dots fits (1.1 mm square printed holes
at provisional 2.50 mm pitch); ONE dot (0.9 mm) was too tight. This supersedes
the initial one-dot report. Original one-dot body openings (18.2 x 7.2 mm six-pin,
13.2 x 7.2 mm four-pin) were closest but still slightly large. Smaller body
coupons have been generated; final header body fit remains pending. Printed tail
fit does not independently establish nominal pitch or final PCB drill diameter.

Subsequent body result: refinement THREE-dot preferred (six-pin 18 x 7 mm,
four-pin 13 x 7 mm), but four-pin outer side slightly snug, inducing a subtle
angle. Six-pin dimension is the current selection; four-pin seating remains
unresolved. New tests relieve only the presumed outboard short edge by 0.2 / 0.4
mm. Pin coupon selection remains TWO-dot (1.1 mm square holes).

## Fit clarification: raised identification dots (2026-09-12)

User subsequently attributed the apparent four-pin tilt to the raised coupon
dots preventing the plates from sitting flush together, and believes the fit is
OK. Retain refinement THREE-dot body openings: six-pin 18.0 x 7.0 mm and four-pin
13.0 x 7.0 mm. Retain original TWO-dot tail holes: 1.1 mm square at provisional
2.50 mm pitch. The outer-edge-relief coupons are superseded diagnostic options;
do not carry their enlargement into the carrier. Final mating/support surfaces
must be flat, with identification outside those surfaces. Integrated header
seating and mating still need an assembly fit check.

## Exposed solder-tail length (2026-09-12)

User supplied 10.17 mm - 6.98 mm as the pin-length measurement: 3.19 mm.
Interpret as exposed solder-tail length beyond the header plastic, for carrier
clearance planning. The two underlying contact datums and which header size was
measured were not explicitly identified; do not infer a confirmed body height,
pin-row offset, or identical tail length for both sizes from this subtraction.

## Pin-row offset measurements (2026-09-12)

User supplied 4.15 mm from the top plastic edge to the far side of the pin, and
clarified 2.77 mm from the opposite plastic edge to the other outside side of
the pin. Interpreted as opposite-edge-to-far-pin-side measurements. With 0.64 mm
pin width in this direction, the inferred row-center offsets are 3.83 mm and
2.45 mm respectively. Their sum implies a 6.28 mm plastic span across that axis
(4.15 + 2.77 - 0.64); this is derived, not a new direct body measurement.

Use these offsets provisionally for the adjustable assembly prototype. The
physical top-side/key orientation and applicability to both header sizes remain
to be checked during assembly. The 7.0 mm accepted body opening is a clearance
aperture, not a measured body span; do not force these offsets to sum to 7.0 mm.

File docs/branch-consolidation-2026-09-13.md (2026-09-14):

# Branch consolidation: 2026-09-13

## Accepted baseline

Main advances from `4fd82fb` to the complete Alpha history through `dc6def9`, including the context cleanup. This is a fast-forward: no competing firmware implementations were combined and no Alpha source, wiring assignments, safety settings or CAD geometry were changed by consolidation. GitHub main was at `c093f05`, two commits behind the previous local main.

The former Alpha branch's 46 commits contain bounded motion/centering, subsequent motor-direction correction, CAD and connector development, test records and context documentation. They are retained in main's normal history. The existing release tag `v1.12.0-rc.1` remains at its original commit; the current source still uses that version string, so record the flashed SHA during testing.

## Older feature work reviewed

The July branches are stacked: motion engine -> battery monitor -> display menu. They forked before the later IBT-2, SSD1309/reset, I2C and local-control fixes. Their three unique commits are preserved under annotated archive tags; they are not merged or represented as current features.

| Former branch | Tip | Archive tag | Disposition |
| --- | --- | --- | --- |
| feature/motion-engine | `7c12f7c` | `archive/2026-09-13/motion-engine` | Current Alpha modes supersede its basic motion implementation. Preserve distinct Random/Flush, calibration, unexpected-limit handling and simulation ideas for deliberate future review. |
| feature/battery-monitor | `e80013e` | `archive/2026-09-13/battery-monitor` | Unique deferred implementation, not obsolete functionality. Preserve ADC filtering, calibration, voltage-state logic and simulation material for a separate port after hardware verification. |
| feature/display-menu | `d403904` | `archive/2026-09-13/display-menu` | Current SSD1309/encoder menus supersede its display/control integration. Preserve edit/confirmation, timeout and simulation ideas for future UX work. |

Concrete incompatibilities: the old motor output function enables only one bridge half per direction, predating `92c20dd`; the old display uses Adafruit SSD1306 with reset disabled, predating the installed SSD1309/U8g2 and GPIO5 reset. The battery/menu commits depend on the older motion implementation and introduce different settings and application gates. Cherry-picking them wholesale would not preserve the current hardware contract.

Archive recovery example (read-only):

```sh
git show archive/2026-09-13/battery-monitor:firmware/crosswind-esp32/battery-monitor.md
```

The archive retains the original source, documentation and test scripts. Those scripts target the old architecture and do not validate main. Battery monitoring, distinct modes and advanced menu behavior are not silently enabled by this cleanup. Current gaps remain in [STATUS](STATUS.md), with future integration tracked in [roadmap](roadmap.md).

## Verification

- ESP32 PlatformIO release build passed on the consolidated Alpha source: Espressif32 7.0.1, Arduino-ESP32 2.0.17, U8g2 2.36.18, BME280 2.3.0 and Unified Sensor 1.1.15.
- RAM: 41,188 / 327,680 bytes; flash: 1,200,277 / 1,310,720 bytes (91.6%). These are build results, not a new hardware acceptance.
- Repository-local Markdown links and whitespace checks are checked during closeout.
- AVR source is unchanged; no local Arduino CLI was available for an AVR build. Existing CI still compiles both controllers.
- No firmware upload, motor/relay exercise, electrical acceptance or CAD regeneration was performed. Direction correction, retention and loaded testing remain pending.

The unrelated user-staged plate-spacer 3MF is preserved outside this consolidation commit.

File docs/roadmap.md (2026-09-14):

# Roadmap

Current implementation and test evidence live in [STATUS](STATUS.md); rationale lives in [DECISIONS](DECISIONS.md).

## Phase 1

- Close out unloaded motion after the direction correction: verify physical direction, both endpoints and start-on-limit behavior; inspect and secure shaft/coupling retention.
- Mount feet and spacers, secure wiring, finalize adjustable endpoint flags/brackets and verify independent mechanical stops and reachable power disconnect.
- Record STOP, ARM/FIRE, fault/recovery, centering and mode-selection results against the flashed commit; resolve safety behavior questions identified in STATUS.
- Validate OLED cold startup, BME280, encoder menus, buttons, RGB and BLE status in the completed enclosure.
- Measure motor startup, no-load and loaded current; finalize branch fuse sizes.
- Validate VEVOR NH113 fit and stability on adjustable thrower-deck rails, then perform conservative loaded sweep and field/runtime tests.
- Fit-check the revised OLED window and assembled PCB-header prototype. Verify IPC-101 board/interface and adapter continuity, then implement explicit panel support while preserving legacy controls and independently validating STOP integration.

## Phase 2 / Alpha X2

- Prototype pitch cradle; select actuator and add pitch limits/feedback with axis-specific fault handling.
- Expand firmware for coordinated yaw/pitch and define distinct RANDOM/FLUSH presentation behavior before implementation.
- Add and validate battery voltage sensing and account for pitch current in the power budget.

## Production Exploration

- Qualify weather-resistant enclosure/connectors and refine serviceable harnesses.
- Establish repeatable calibration, a validated universal rail kit and durability/runtime evidence.
- Decide the production controller/fallback policy and refine product identity/model naming.

Use the [archived feature-work assessment](branch-consolidation-2026-09-13.md) when planning battery sensing, distinct modes or menu enhancements; port selectively against current hardware and safety behavior.

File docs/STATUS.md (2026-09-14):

# CrossWind status

Evidence snapshot: 2026-09-13, Alpha implementation reviewed through `606cace`, consolidated onto main through `dc6def9`. This distinguishes source implementation, reported physical observations and plans; it is not a new bench acceptance record.

See the [branch consolidation record](branch-consolidation-2026-09-13.md) for accepted history, archived feature work and the successful ESP32 build. Archived battery/motion/menu implementations are not active main features.

## Confirmed / implemented

Phase 1 yaw is the active prototype. ESP32 source identifies itself as `v1.12.0-rc.1`, with later changes under that same version string. Phase 2 pitch and IPC-101 panel integration are future work. See [configuration](../firmware/crosswind-esp32/src/config.h), [firmware overview](../firmware/crosswind-esp32/README.md) and [adapter plan](../electrical/ipc101-adapter-plan.md).

## Bench-tested

- [2026-08-14 sweep record](../testing/sweep-test-log.md) records no-thrower passes for endpoint reversal, STOP, stuck-limit, both-limit, travel-timeout and timed centering on the Alpha mechanism (`24c9aa8`, `946dc68`). This does not validate every later revision.
- [2026-09-10 results](../testing/2026-09-10-bench-results.md) report motor motion/reversal, both/stuck-limit faults and throwing already working. These are user reports without flashed SHA, PWM, supply, current or runtime. The later follow-up identifies reversed physical motor direction, superseding the initial suspected limit-wiring mismatch.
- `3563fba` corrects output direction in source. The same record explicitly says flashing and physical verification are pending. Field readiness remains unaccepted.

## Mechanically completed

An operating bench mechanism and physical panel/connector fit trials are evidenced, but no complete mechanical acceptance record exists. September 10 records feet mounting and spacer installation pending, plus possible rod-to-motor or flange-to-rod slippage. [Connector notes](../cad/phase-1/controller-connector/README.md) record accepted cable/header coupon fits and user-confirmed hook mating, not final carrier retention. An [assembled header fit prototype](../cad/phase-1/controller-connector/PCB_Header_Assembly_Instructions.md) exists (`e9f0994`); assembly acceptance is pending. The [OLED window correction](../cad/phase-1/side-panel/README.md) (`606cace`) still needs a reprint/physical check.

## Electrically completed

Powered YL-99 module levels were recorded at approximately 3.2 V clear and 0 V pressed in the [limit harness standard](../electrical/limit-switch-harness.md). Motor/limit operation is reported above; the SSD1309 is documented as the verified Alpha display in the [OLED standard](../electrical/oled-lid-harness.md). These do not establish completion of every harness, fuse, enclosure or power-system checklist. Exact OLED JST series/colors and final branch fuse sizes remain unrecorded. No IPC-101 adapter electrical validation is recorded.

## Firmware implemented

- [motor.cpp](../firmware/crosswind-esp32/src/motor.cpp): IBT-2 dual-enable drive, mutually exclusive PWM, zero-output stop, ramp and reversal dead time (`92c20dd`). Current inverted mapping drives logical RIGHT via LPWM and LEFT via RPWM (`3563fba`).
- [modes.cpp](../firmware/crosswind-esp32/src/modes.cpp): bounded sweep and timed centering. RANDOM and FLUSH use the same sweep routine; distinct behavior is explicitly deferred in the September bench record. Centering estimates time, not sensed position.
- [main.cpp](../firmware/crosswind-esp32/src/main.cpp) and [inputs.cpp](../firmware/crosswind-esp32/src/inputs.cpp): encoder menus (Motor, Mode, Environment, Diagnostics, About), speed edit, stopped-only local mode/direction selection, ARM/FIRE gating, fault handling, BLE STOP/disconnect output cancellation (`b3b4dac`, `c093f05`). Boot is stopped/unarmed; encoder press does not fire.
- [display.cpp](../firmware/crosswind-esp32/src/display.cpp) and [environment.cpp](../firmware/crosswind-esp32/src/environment.cpp): SSD1309 reset/retry and 100 kHz shared I2C handling; BME280 dual-address initialization/retry and rejection of implausible readings (`1f1f832`, `a95ddf6`, `accb1ac`). RGB status and nonblocking relay pulses are present.
- [storage.cpp](../firmware/crosswind-esp32/src/storage.cpp): Preferences mode, speed and last-fault history. Stored last-fault history is not automatically restored as an active fault at boot.
- E-stop, battery/current sensing and pitch pins are disabled placeholders; session timeout, overcurrent protection and IBT-2 diagnostic test mode are disabled. Automatic triggering is disabled. AVR remains a [legacy fallback without Alpha parity](../firmware/crosswind-arduino/README.md).

## Not yet verified

Corrected physical direction and both endpoints/start-on-limit behavior; shaft/coupling retention; feet/spacers/stops and complete enclosure/harness installation; loaded NH113 fit, stability and sweep; motor startup/running current, fuse selection, runtime and field durability. [Motor](../testing/motor-test-log.md), [battery](../testing/battery-runtime-log.md) and [field](../testing/field-test-notes.md) logs are blank templates. Repeat control/relay/fault and cold-start OLED/BME280 checks on the actual flashed revision and enclosed wiring. IPC-101 key scanning, RGB and independent STOP integration are not implemented here.

## Known issues / open questions

- Older [pre-motor readiness report](../firmware/crosswind-esp32/docs/testing/Alpha_PreMotor_Bench_Readiness.md) maps RIGHT to RPWM, predating `3563fba`; use current motor source and firmware README for output mapping. Its historical build result is not a current build result.
- [Fault matrix](../firmware/crosswind-esp32/fault-matrix.md) says temperature must fall before clearing. main.cpp's clear gate checks limits/E-stop only; an ongoing temperature fault is subsequently relatched. `ENV ERR` is a warning, not a temperature fault. Clarify/test this behavior before relying on sensor loss as protection.
- Software STOP/BLE disconnect cancels motion and active relay but does not explicitly clear `systemArmed`; it is not an installed hardware E-stop. The unexpected opposite endpoint is not an immediate sweep fault (September record and modes.cpp). These require deliberate safety review, not a documentation-only code change.
- [Mechanical dimensions](../mechanical/phase-1/dimensions.md) and [cut list](../mechanical/phase-1/cut-list.md) agree on nominal 28-inch base, 20-inch thrower deck and 12-inch bearing, but are not measured as-built acceptance. No conflicting nominal base/deck dimensions were found. Motor thread, engagement and retention interface remain unverified.
- Broad measure-the-OLED TODOs in the [mechanical overview](../mechanical/phase-1/README.md) lag the partial measurements in [side-panel layout](../cad/phase-1/side-panel-layout.md). That layout leaves overall size undefined while the prototype uses 150 x 100 x 3 mm provisionally. Hole datums/clearances and the latest window shift still need fit verification; do not turn these into final dimensions.
- The [IPC-101 adapter plan](../electrical/ipc101-adapter-plan.md) preserves successive fit reports: later two-dot tail holes and three-dot body openings supersede earlier choices; raised dots, not confirmed tightness, explained tilt. Later measurements partly supersede its initial missing-dimensions list. Provisional pitch/offsets do not release a PCB footprint. Its sibling-project interface references are not self-contained CrossWind evidence and need verification before implementation.
- The existing 6+6+4 Alpha connector arrangement, official five-signal OLED standard and planned IPC-101 4+6 plus separate STOP are different contexts. Installed cavity mapping/adapter continuity must be recorded before migration; do not merge these pinouts. The OLED standard lists SCL at cavity 3 and SDA at 4; unordered signal lists elsewhere are not pin numbering.
- Old calibration messages in [limits.cpp](../firmware/crosswind-esp32/src/limits.cpp) say safety-only and remain placeholders; current endpoints also command reversal. AVR's normally-closed limit wiring is legacy, not the Alpha powered-module standard. Historical diagnostics, fit coupons and fallback code are retained; age alone does not establish dead code.

## Immediate next milestone

Close out unloaded Alpha motion: inspect and secure both shaft interfaces, verify limit identities with motor power off, flash/record the direction-corrected revision, verify low-speed travel/reversal and starts at both endpoints, then record STOP, trigger inhibition and fault recovery. Confirm independent stops, mounted feet/spacers and accessible cutoff before loaded tests. Follow [September closeout](../testing/2026-09-10-bench-results.md) and [safety notes](safety-notes.md); simulate timeouts without stalling against a stop. Future work is tracked in [roadmap](roadmap.md).

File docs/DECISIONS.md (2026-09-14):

# Engineering decisions

Durable choices supported by repository evidence or the explicit context task. Status distinguishes an accepted direction from completed hardware. Current verification gaps belong in [STATUS](STATUS.md); future work belongs in [roadmap](roadmap.md). Revisit with new evidence, preserving the reason for any superseding decision.

## Decision: ESP32 is the Alpha controller; retain AVR as legacy

Status: Established for Alpha.

Date or commit if known: `946dc68`.

Decision: Use the modular ESP32 PlatformIO project for Alpha; retain AVR separately without assuming feature or safety parity.

Reason: The Alpha motion record and AVR README explicitly distinguish validated ESP32 motion from the older fallback.

Consequences: AVR requires separate endpoint, timeout and centering review/porting before Alpha use. Production fallback policy remains open.

Revisit when: A concrete controller requirement or separately validated AVR port warrants reconsideration.

Evidence: [ESP32 overview](../firmware/crosswind-esp32/README.md), [AVR limitations](../firmware/crosswind-arduino/README.md).

## Decision: IBT-2 drive and installed direction mapping

Status: Implemented; latest mapping awaits physical verification.

Date or commit if known: `92c20dd`, `3563fba`.

Decision: Use both bridge enables during drive, one PWM output at a time, zero all outputs on stop, and preserve ramp/dead time. Invert the output mapping for the reported installed motor direction.

Reason: The bridge needs both halves enabled; the later bench report identified logical/physical travel reversal.

Consequences: Logical limits keep their identities. Do not also swap motor leads; verify both physical endpoints after flashing.

Revisit when: Motor/linkage/wiring changes or new measured direction evidence.

Evidence: [motor.cpp](../firmware/crosswind-esp32/src/motor.cpp), [bench follow-up](../testing/2026-09-10-bench-results.md).

## Decision: Powered limits define normal reversal boundaries

Status: Established Alpha standard.

Date or commit if known: `4fd82fb`, `24c9aa8`, `946dc68`.

Decision: Use powered 3.3 V active-LOW YL-99 endpoints with the Deutsch DT six-pin harness; reserve lower/upper conductors for future pitch. Use separate mechanical stops.

Reason: Module levels were bench-verified; normal endpoint reversal and fault protection are both required.

Consequences: GPIO34/35 rely on module pull-ups. Open wires are not automatically detected. Maintain release/both-limit/travel protections and inspect continuity.

Revisit when: Different switch hardware, supervised wiring requirements or the pitch implementation requires an explicit revision.

Evidence: [Harness standard](../electrical/limit-switch-harness.md), [switch layout](../mechanical/phase-1/limit-switch-layout.md).

## Decision: SSD1309 five-signal harness and shared BME280 bus

Status: Established Alpha standard.

Date or commit if known: `3d319ab`, `1f1f832`, `a95ddf6`.

Decision: Retain the verified Hosyond 2.42-inch SSD1309, 3.3 V supply, GPIO5 reset and canonical five-position OLED harness; share I2C with BME280.

Reason: Cold-start and shared-bus fixes establish reset, timing/recovery and plausible environmental readings as working behavior to preserve.

Consequences: Use the numbered harness table, not prose signal order. Record exact connector family before buying replacements; measure enclosure interfaces. BME280 is telemetry, not a certified safety instrument.

Revisit when: A measured replacement interface or tested panel migration requires a deliberate change.

Evidence: [OLED standard](../electrical/oled-lid-harness.md), [safety](safety-notes.md), [display source](../firmware/crosswind-esp32/src/display.cpp).

## Decision: Local control and scoped Alpha modes

Status: Implemented; distinct Random/Flush deferred.

Date or commit if known: `c093f05`; 2026-09-10 record.

Decision: Operate locally with encoder menus and dedicated ARM/FIRE; BLE is optional. Keep RANDOM/FLUSH as sweep aliases for scoped Alpha testing and timed centering as an estimate.

Reason: Local operation is a requirement; the September record explicitly accepts shared sweep behavior until Alpha X2.

Consequences: Encoder selection never fires. Do not claim distinct patterns, position feedback or automatic throws; preserve trigger interlocks.

Revisit when: Defined Alpha X2 presentation behavior and validation criteria are available.

Evidence: [Requirements](product-requirements.md), [mode implementation](../firmware/crosswind-esp32/src/modes.cpp), [bench scope](../testing/2026-09-10-bench-results.md).

## Decision: Fused power buses and dry-contact triggering

Status: Documented architecture; assembly acceptance pending.

Date or commit if known: Date not established.

Decision: Plan tool-battery input through a main fuse and high-current 12 V buck, with branch fuses and a separate 5 V electronics buck; keep the thrower relay dry-contact in parallel with the factory pedal.

Reason: Separate load branches support protection/service; the relay emulates a switch without injecting voltage into the pedal circuit.

Consequences: Measure current before final fuse sizing, maintain common power/logic ground and reachable disconnect, and continuity-check the actual pedal before connection.

Revisit when: Measured loads or confirmed thrower interface changes require a revised power/trigger design.

Evidence: [Power](../electrical/power-system.md), [fuses](../electrical/fuse-plan.md), [trigger](../electrical/thrower-trigger.md).

## Decision: Thrower deck and adjustable fitment

Status: Required terminology and established fitment strategy.

Date or commit if known: Terminology: this context task, 2026-09-13; fitment date not established.

Decision: Call the moving thrower-support platform the thrower deck. Retain adjustable mounting/rails with NH113 as the first fitment target.

Reason: The task defines the term; requirements and fitment notes call for support beyond a single thrower footprint.

Consequences: Older top-plate wording means thrower deck in this context. Nominal dimensions are not proof of a measured interface or universal compatibility; preserve adjustability and verify load paths.

Revisit when: Measured fitment or structural evidence requires a deliberate mechanical revision.

Evidence: [Requirements](product-requirements.md), [NH113 fitment](../mechanical/phase-1/vevor-nh113-fitment.md).

## Decision: IPC-101 migration uses a separate adapter

Status: Selected development direction; not integrated.

Date or commit if known: `bd85eef`, `8922fa8`, `a77c183`, `e9f0994`.

Decision: Develop IPC-101 with four-position controls and six-position display connections using matching hook-retained PCB headers, plus a distinct isolated STOP connector. Preserve the current Alpha harness.

Reason: The recorded selection supports a replaceable equipment adapter for Alpha and later IPC-100; user-confirmed mating supersedes the loose middle-header concept.

Consequences: No TCA8418 driver or STOP integration exists in current firmware. Preserve independent panel branches; verify cavity orientation, continuity and provisional geometry before releasing hardware. Superseded fit coupons remain diagnostic history.

Revisit when: Assembly/PCB arrival testing or verified interface evidence changes the design.

Evidence: [Adapter plan](../electrical/ipc101-adapter-plan.md), [connector development](../cad/phase-1/controller-connector/README.md).

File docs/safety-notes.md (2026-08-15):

# Safety Notes

- Keep hands clear of the rotating top plate, motor linkage, roller switch striker, and thrower arm.
- Always bench test without the thrower mounted after firmware or wiring changes.
- Use a main fuse near the battery.
- Use branch fuses for the thrower, wobbler motor, actuator, and 5V electronics supply.
- Verify the ESP32 and motor driver share ground.
- Do not feed more than 3.3V into ESP32 analog or GPIO pins.
- Do not power the wiper motor from the 5V buck converter.
- Do not inject voltage into the thrower foot-pedal trigger circuit; relay contacts must be dry contact only.
- Add a reachable power disconnect before field testing.
- Secure the base before powered motion.
- Treat stored faults as useful evidence; investigate before clearing and retesting.
- Treat trigger testing like live thrower testing: unload the thrower, point it safely, and keep people clear.
- Confirm the VEVOR NH113 pedal wires with a continuity test before wiring Crosswind in parallel.
- Crosswind Alpha uses a BME280 for enclosure temperature, humidity, and pressure telemetry. It is not a certified safety instrument.
- Keep the BME280 away from the BTS7960 heat sink and motor driver. Do not mount it directly against the case wall, where sun or surface heating can distort readings.
- Temperature faults stop the motor only at `TEMP_FAULT_F`; investigate enclosure airflow, motor driver heating, and wiring before clearing a temperature fault.
- YL-99 limit switches command normal end-of-travel reversal and also serve as safety inputs. Do not use their roller arms as mechanical hard stops.
- Mount separate rubber or metal stops beyond the switch actuation points so a control or switch failure cannot overtravel the mechanism.
- Normal single-limit activation stops the current direction and reverses away after dead time. Both active, failure to release, or travel timeout must stop motor output, disarm the system, block relay firing, and latch a fault.

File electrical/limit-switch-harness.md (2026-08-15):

# Limit Switch Harness Standard

This document is the source of truth for the Crosswind limit switch cable, connector, and conductor colors. The standard supports the current single-axis Alpha assembly and the future dual-axis assembly without replacing or rewiring the harness.

## Cable and Connector

- Cable: 6-conductor
- Connector: Deutsch DT 6-pin
- Switch type: powered YL-99 limit switch module
- Module supply: Red 3.3 V and Black shared ground
- Normal, unactuated OUT: HIGH
- Actuated OUT: LOW (module shorts OUT to ground)

## Pinout

| Deutsch DT pin | Conductor | Function | Alpha use |
| ---: | --- | --- | --- |
| 1 | Green | Left limit switch | Connected |
| 2 | Blue | Right limit switch | Connected |
| 3 | White | Lower / Axis 2 Down limit switch | Terminated, unused |
| 4 | Yellow | Upper / Axis 2 Up limit switch | Terminated, unused |
| 5 | Black | Shared ground for all limit switch modules | Connected |
| 6 | Red | Shared 3.3 V supply for all limit switch modules | Connected |

Red is dedicated to the regulated ESP32 3.3 V rail for the limit switch modules. Do not connect it to 5 V, battery voltage, or another supply.

## Connector Diagram

The following is the mating-face view with the latch at the top. Always confirm the molded cavity numbers on the actual Deutsch housing before crimping; housing illustrations can be mirrored when viewed from the wire side.

```text
                    LATCH
              +-----------------+
              |  1     2     3  |
              | GRN   BLU   WHT  |
              | Left  Right Lower|
              |                 |
              |  4     5     6  |
              | YEL   BLK   RED  |
              | Upper GND  3V3   |
              +-----------------+
                 MATING FACE
```

## Switch Wiring Diagram

Each powered limit module receives 3.3 V on Red and ground on Black. Its onboard pull-up holds the assigned OUT signal HIGH while clear, and the switch shorts OUT to Black ground when pressed.

```text
ESP32/input side                         Limit-switch side

ESP32 GPIO34 <--- Green  (pin 1) <--- Left module OUT
ESP32 GPIO35 <--- Blue   (pin 2) <--- Right module OUT
Future input <--- White  (pin 3) <--- Lower module OUT
Future input <--- Yellow (pin 4) <--- Upper module OUT

ESP32 GND ----> Black (pin 5) ----+---- module GND (all modules)
ESP32 3.3 V --> Red   (pin 6) ----+---- module VCC (all modules)

Each module provides its onboard 3.3 V pull-up. A pressed module shorts OUT to GND.
```

| Condition | Contact/cable state | ESP32 input |
| --- | --- | --- |
| Normal, switch not actuated | Module OUT powered HIGH | HIGH / clear |
| Limit switch actuated | Module shorts OUT to Black ground | LOW / active |
| Signal conductor broken or disconnected | GPIO34/GPIO35 has no internal pull-up | Undefined; treat as a wiring fault during inspection |
| Red 3.3 V or Black ground broken | Module state is not trustworthy | Treat as a wiring fault during inspection |

This powered active-LOW module arrangement does **not** provide open-wire fault detection: a broken OUT wire leaves GPIO34/GPIO35 electrically undefined. Inspect and continuity-test the harness before operation. Additional controller-side bias and end-of-line monitoring or different hardware would be required for automatic broken-wire detection.

## ESP32 Pull-up Compatibility

The current Alpha GPIO assignments remain GPIO34 for Left and GPIO35 for Right. Those pins do not have internal pull-ups, so Alpha relies on the installed YL-99 modules' onboard pull-ups. Bench measurements verified approximately 3.2 V/HIGH while released and 0 V/LOW while pressed; no additional external resistors are required for the installed modules.

Before powered motion, confirm the installed firmware reports HIGH/clear for each unactuated module and LOW/active when pressed. The firmware must use `LIMIT_ACTIVE_STATE = LOW`.

## Alpha Assembly

During Alpha, connect only:

- Green, pin 1: Left limit
- Blue, pin 2: Right limit
- Black, pin 5: shared ground
- Red, pin 6: shared regulated 3.3 V

Crimp, seal, and terminate White and Yellow in their assigned connector cavities, but leave them electrically unused. Insulate and secure their equipment-side ends separately so they cannot contact ground, power, or one another.

## Harness Assembly Procedure

1. Label both cable ends and orient each Deutsch DT housing by its molded cavity numbers.
2. Crimp the six conductors to the correct contacts and install the connector seals and wedge locks.
3. Connect every module `OUT` to its assigned Green, Blue, White, or Yellow conductor.
4. Connect every module `GND` to Black and every module `VCC` to Red.
5. Connect Red only to regulated ESP32 3.3 V. During Alpha, isolate the equipment-side White and Yellow conductors.
6. Add strain relief and route the cable clear of bearings, linkages, crank arms, rotating plates, and pinch points.
7. With power disconnected, verify pin-to-pin continuity and confirm there are no shorts between adjacent conductors.
8. With controller power only, confirm Red-to-Black measures approximately 3.3 V at the harness and each module powers normally.
9. Confirm each OUT input is HIGH normally and LOW when its switch is pressed. With power removed, continuity-test each OUT conductor; do not use a disconnected live input as a valid state because GPIO34/GPIO35 will float.
10. Do not enable motor power until all continuity and input-state checks pass.

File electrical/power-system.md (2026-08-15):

# Power System

## Tool Battery Input

Current Alpha power planning assumes a 20V/24V tool battery input. Do not feed that voltage directly to the ESP32, relay module, sensors, BTS7960 logic, or 12V loads.

## Main Fuse

Place a main fuse close to the tool battery positive terminal, before the high-current buck converter. Size it for the expected total current and wiring gauge.

## Branch Fuse Block

Use a small branch fuse block so each load can be protected and serviced independently.

## 12V Bus

A high-current buck converter steps the 20V/24V input down to a fused 12V bus. The 12V bus feeds BTS7960 motor power and the thrower power output. Do not power the wiper motor from the 5V buck.

## Thrower Circuit

The thrower should have its own fused 12V branch. Keep its high-current wiring physically separated from low-voltage control wiring where practical.

The thrower trigger relay does not power the thrower. It only closes a dry contact across the same two wires used by the factory foot pedal.

## Wobbler Motor Circuit

The BTS7960 motor supply branch comes from the 12V bus and powers the Mitsubishi Outlander rear wiper motor. Start with conservative fuse sizing based on measured current.

## Actuator Circuit

Reserve a fused branch for the future pitch actuator. Expect startup and stall current to be higher than running current.

## 5V Buck Converter Circuit

A fused 5V buck converter is fed from the 12V bus. The 5V bus feeds ESP32 `VIN`/`5V`, the relay module, BTS7960 logic, and support modules as appropriate. ESP32 `3V3` feeds the Hosyond 2.42-inch SSD1309 OLED, BME280, powered YL-99 modules, and small logic sensors. The OLED remains on 3.3 V even though its listing indicates 3.3-5 V compatibility. Its 3.3 V and ground conductors run through the official five-position JST lid harness alongside SDA, SCL, and GPIO5 reset. All grounds must be common.

## Trigger Relay Circuit

The ESP32 powers only the relay module input side. The relay contact side is isolated and connects to the VEVOR NH113 pedal circuit as `COM` and `NO`. Keep this circuit dry-contact only; never inject ESP32 or bus voltage into the thrower foot-pedal trigger circuit.

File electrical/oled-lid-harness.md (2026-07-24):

# OLED Lid Harness Standard

This document is the source of truth for the Crosswind Alpha OLED lid harness. The verified production-standard display is the Hosyond 2.42-inch 128x64 monochrome OLED with SSD1309 controller and five electrical connections.

## Cable and Connector

- Harness: 5-conductor lid harness
- Connector: 5-position JST connector
- Connector family and pitch: match the installed Alpha JST mating pair; record the exact manufacturer series before ordering replacements
- Display supply: regulated ESP32 3.3 V
- Logic: 3.3 V I2C
- Display address: normally `0x3C`; firmware also diagnoses `0x3D`

The `RES` conductor is part of the official harness and is required for firmware-controlled display reset and reliable cold-power startup.

## Connector Pinout

Pin numbers are viewed from the mating face of the controller-side connector with the latch/key in its normal top orientation. Verify the molded cavity order for the selected JST series before crimping.

| Pin | Signal | ESP32 connection | OLED connection | Notes |
| ---: | --- | --- | --- | --- |
| 1 | GND | System ground | `GND` | Shared logic ground |
| 2 | +3.3 V | ESP32 `3V3` | `VCC` | Do not use 5 V in Crosswind |
| 3 | OLED SCL | GPIO22 | `SCL` | Shared I2C bus |
| 4 | OLED SDA | GPIO21 | `SDA` | Shared I2C bus |
| 5 | OLED RESET | GPIO5 | `RES` | Active LOW; firmware controlled |

Conductor colors are not standardized until the installed cable colors are recorded. Label both ends by signal and cavity number; never infer function from color alone.

## Wiring Diagram

```text
ESP32 / controller                 JST 5-pin lid harness                 SSD1309 OLED

System GND  --------------------------- pin 1 -------------------------- GND
3V3         --------------------------- pin 2 -------------------------- VCC
GPIO22 SCL  --------------------------- pin 3 -------------------------- SCL
GPIO21 SDA  --------------------------- pin 4 -------------------------- SDA
GPIO5 RES   --------------------------- pin 5 -------------------------- RES
```

The BME280 remains on the controller side of the shared GPIO21/GPIO22 I2C bus. Adding OLED reset does not change the BME280 or any encoder, button, motor, relay, or limit-switch wiring.

## Harness BOM

| Qty | Item | Requirement |
| ---: | --- | --- |
| 1 | Five-position JST plug housing | Must mate with installed controller/lid connector |
| 1 | Five-position JST receptacle housing | Matching series and pitch |
| 10 | Crimp contacts | Correct contacts and wire range for selected JST series |
| 1 | Five-conductor cable or five discrete conductors | Flexible stranded wire suitable for lid movement |
| 2 | Harness labels | Identify connector, pin numbers, and signal names |
| As required | Sleeving and strain relief | Protect conductors at lid and enclosure transitions |

Record the exact JST series, pitch, housing part numbers, contact part numbers, conductor gauge, cable colors, and finished length after measuring the installed Alpha hardware. Do not order by the generic term “JST” alone.

## Fabrication Procedure

1. Cut five conductors to the measured lid-routing length, including service loop and strain-relief allowance.
2. Label both ends `GND`, `3V3`, `SDA`, `SCL`, and `RES`.
3. Crimp contacts with the tooling specified for the selected JST series and wire gauge.
4. Insert each contact into its assigned cavity and perform a light pull test.
5. Verify cavity numbering from the mating face before joining the connector halves.
6. Perform point-to-point continuity testing for all five conductors.
7. Confirm no conductor is shorted to an adjacent cavity.
8. With the OLED disconnected, confirm pin 2 measures approximately 3.3 V relative to pin 1.
9. Connect the OLED and confirm the Serial I2C scan reports it, normally at `0x3C`.
10. Cold-cycle controller power without opening Serial Monitor and confirm the startup test and normal interface appear.

## Acceptance Criteria

- All five signals pass continuity testing.
- No pin-to-pin shorts are present.
- OLED power is 3.3 V.
- GPIO5 reaches the OLED `RES` input.
- Firmware reports `SSD1309 display ready` at the detected I2C address.
- The display starts on a cold power-up and continues to operate while the BME280 shares the bus.

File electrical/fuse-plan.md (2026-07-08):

# Fuse Plan

Initial fuse sizes should be conservative and updated after current measurements.

| Branch | Starting Point | Notes |
| --- | --- | --- |
| Tool battery input | TBD | Main fuse before high-current buck converter |
| 12V thrower branch | TBD | Follow thrower documentation |
| 12V wobbler motor branch | TBD | Measure wiper motor startup and running current |
| Pitch actuator | TBD | Phase 2 |
| 5V electronics | 1-3A | Fused buck from 12V bus; do not power motor from this branch |

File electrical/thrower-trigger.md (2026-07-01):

# Thrower Trigger Wiring

The VEVOR NH113 factory foot pedal appears to be a simple two-wire momentary switch using black and white wires.

- Pedal released: open circuit.
- Pedal pressed: black and white shorted together.

Confirm this with a continuity meter before wiring Crosswind to the thrower.

## Crosswind Relay Concept

Crosswind triggers the thrower by closing a relay contact in parallel with the factory pedal.

- Relay `COM` connects to one pedal wire.
- Relay `NO` connects to the other pedal wire.
- Factory pedal remains connected and usable.
- ESP32 GPIO drives only the relay module input.
- ESP32 never sends voltage into the pedal circuit.
- Relay contacts are used as a dry contact only.

## ESP32 Control

Default firmware pin:

- `GPIO14` -> opto-isolated relay module input

Configurable settings live in `firmware/crosswind-esp32/src/config.h`:

- `THROWER_TRIGGER_PIN`
- `TRIGGER_PULSE_MS`
- `MIN_TRIGGER_INTERVAL_MS`
- `TRIGGER_ACTIVE_STATE`
- `ENABLE_THROWER_TRIGGER`
- `ALLOW_TRIGGER_WHEN_STOPPED`

Current Alpha firmware also requires the ARM button to put the controller in `ARMED` state before the FIRE / TEST button or BLE trigger commands can pulse the relay.

## Safe Test Procedure

1. Disconnect thrower power.
2. Confirm pedal black/white wires with a continuity meter.
3. Wire relay `COM` and `NO` in parallel with the pedal.
4. Confirm the factory pedal still works.
5. Power ESP32 and verify Serial diagnostics show trigger inactive.
6. Press FIRE while `SAFE` and confirm the relay is blocked.
7. Press ARM, then test the relay with the thrower unloaded and pointed safely.
8. Confirm repeated trigger commands are blocked by `MIN_TRIGGER_INTERVAL_MS`.

Do not use thrower triggering during Phase 1 movement testing unless the thrower is secured, unloaded, and pointed in a safe direction.

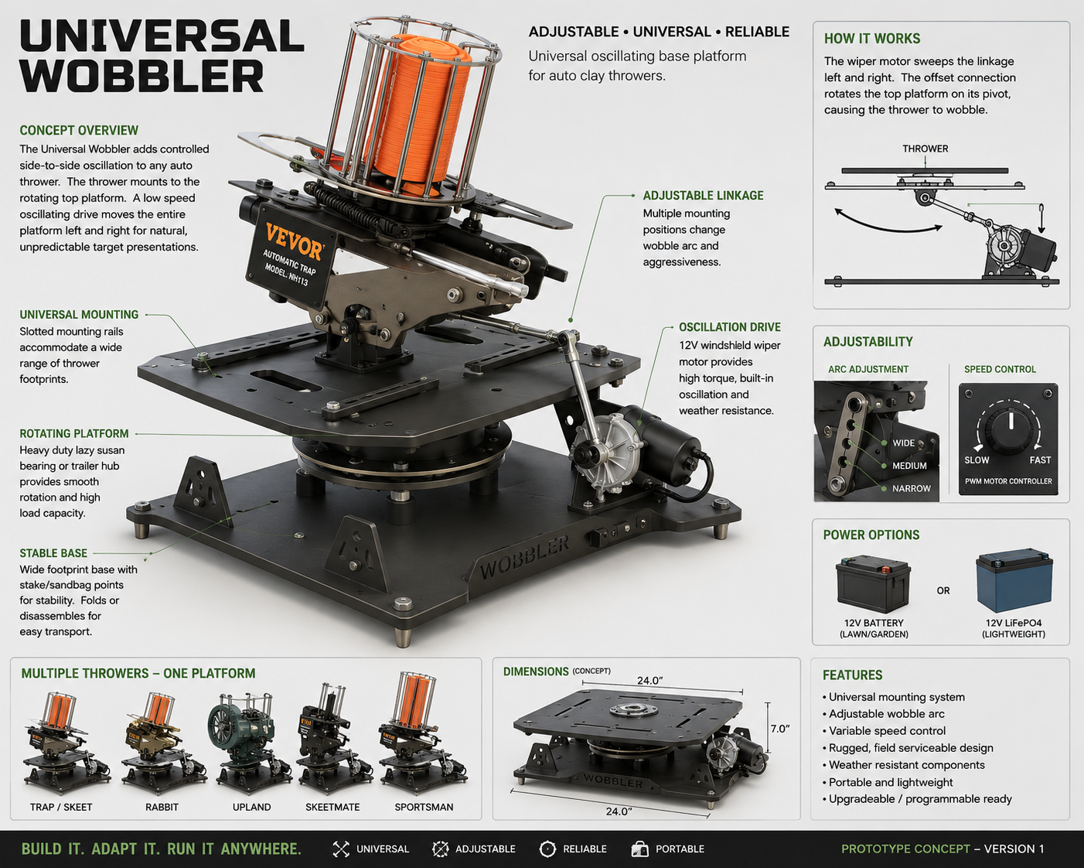
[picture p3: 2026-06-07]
mechanical/sketches/universal_wobbler_concept_poster.png

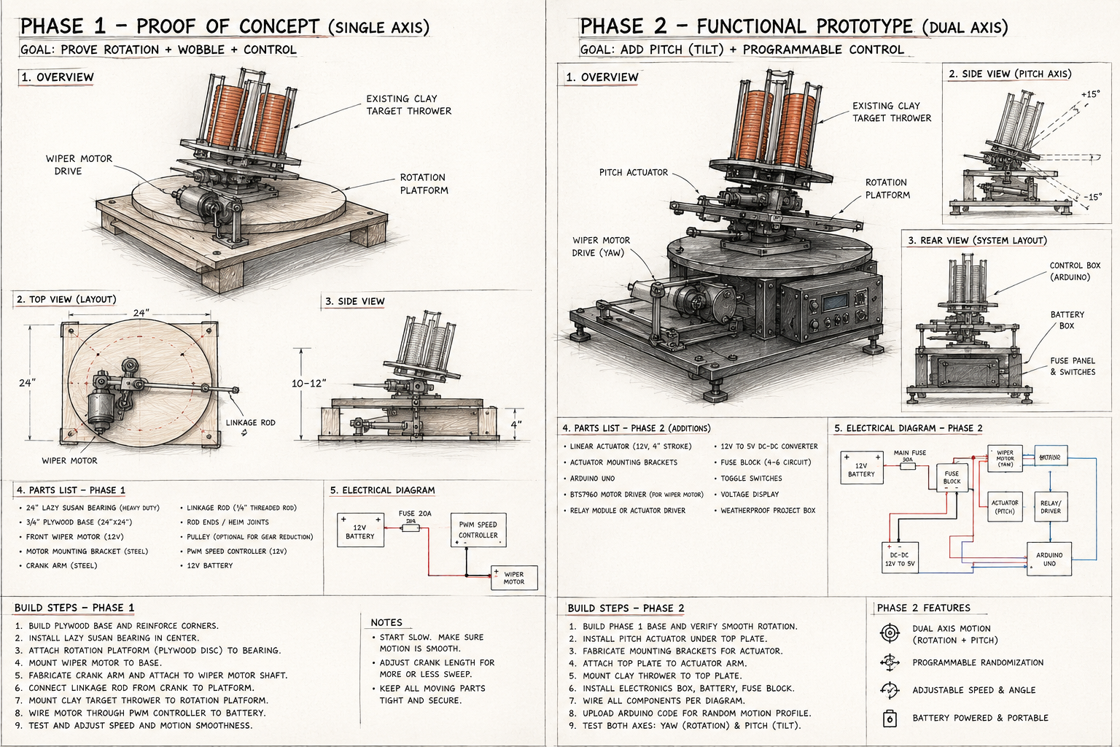
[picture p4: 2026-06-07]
mechanical/sketches/phase_1_phase_2_sketch_plan.png

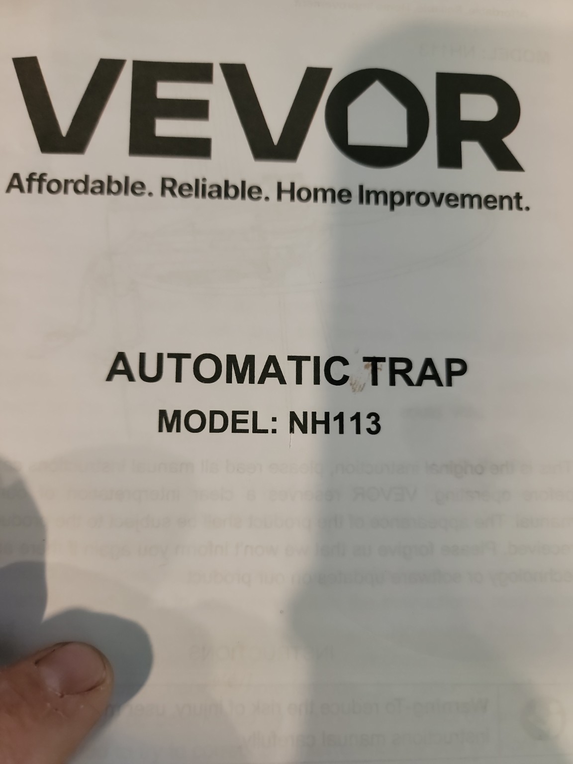
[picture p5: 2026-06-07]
docs/reference/original-thrower/vevor_nh113_reference_1.jpg

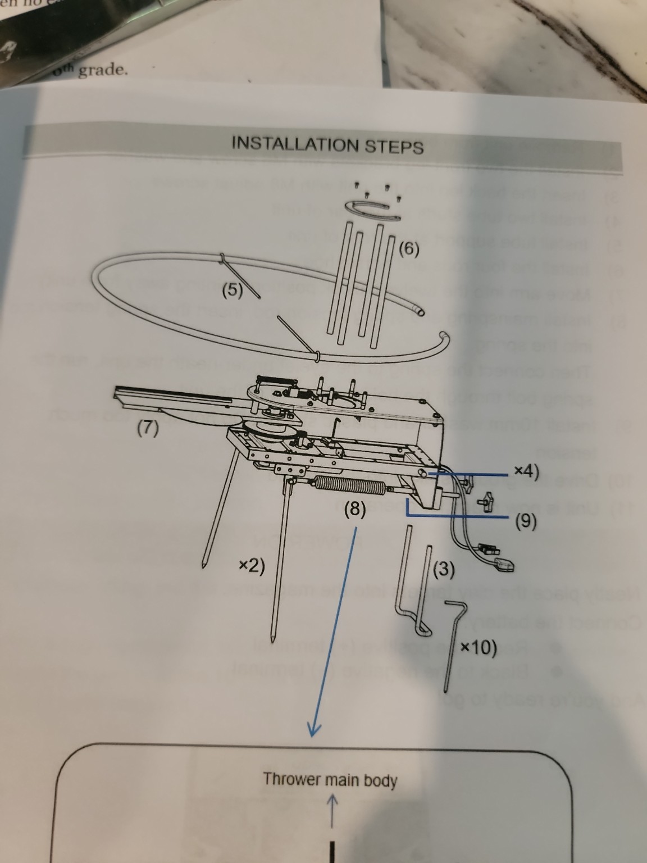
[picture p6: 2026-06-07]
docs/reference/original-thrower/vevor_nh113_reference_2.jpg

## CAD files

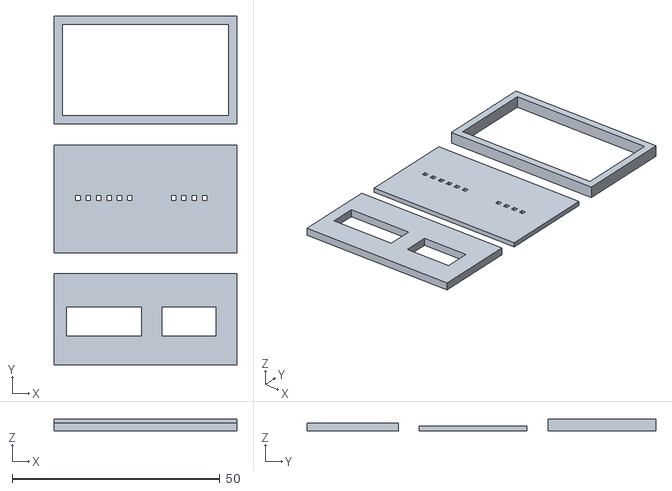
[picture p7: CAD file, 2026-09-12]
cad/phase-1/controller-connector/PCB_Header_Assembly_All_PRINT.stl
44.0 x 84.0 x 3.00

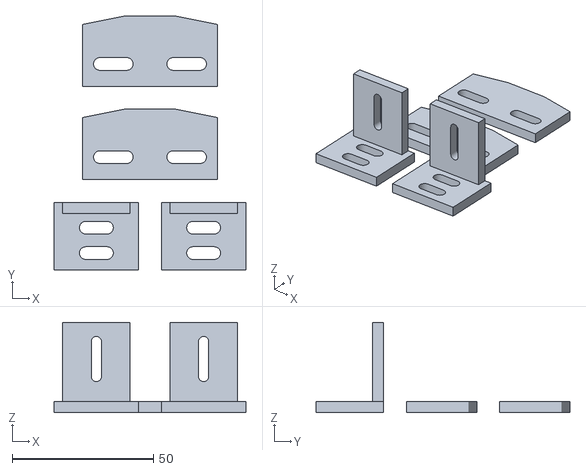
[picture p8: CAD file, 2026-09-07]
cad/phase-1/compact-edge-limits/complete_two_endpoint_kit.stl
68.0 x 90.0 x 32.0

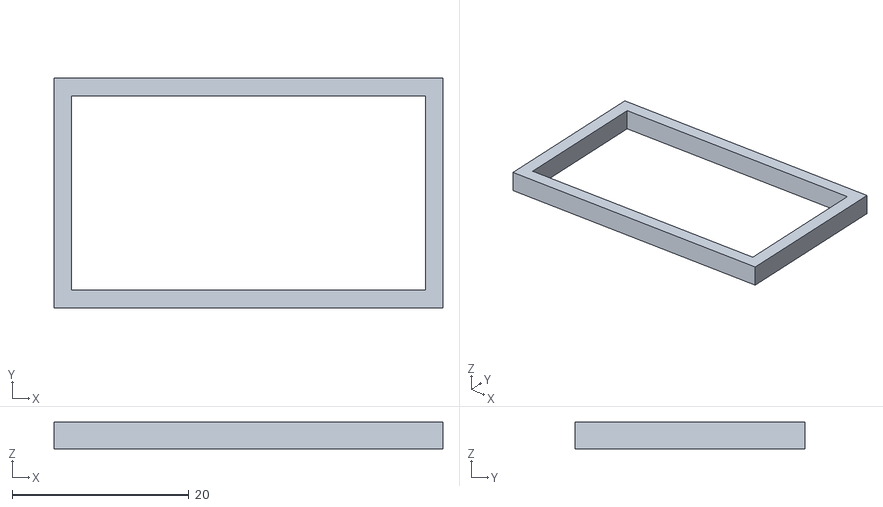
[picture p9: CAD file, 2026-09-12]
cad/phase-1/controller-connector/PCB_Header_Assembly_Stand_PRINT.stl
44.0 x 26.0 x 3.00

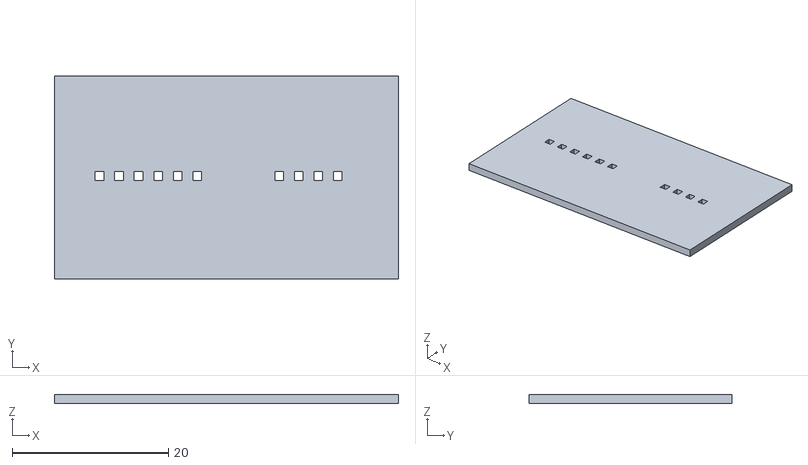
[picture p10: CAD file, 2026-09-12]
cad/phase-1/controller-connector/PCB_Header_Assembly_Pin_Plate_PRINT.stl
44.0 x 26.0 x 1.20

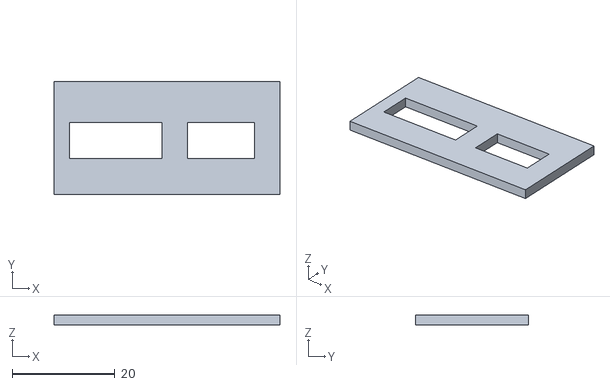
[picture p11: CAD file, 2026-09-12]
cad/phase-1/controller-connector/PCB_Header_Assembly_Guide_PRINT.stl
44.0 x 22.0 x 2.00

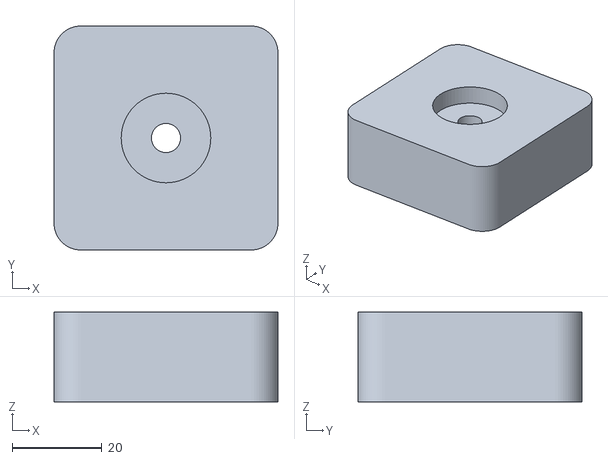
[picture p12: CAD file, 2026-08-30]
cad/phase-1/base-foot/crosswind_alpha_base_foot.stl
50.0 x 50.0 x 20.0

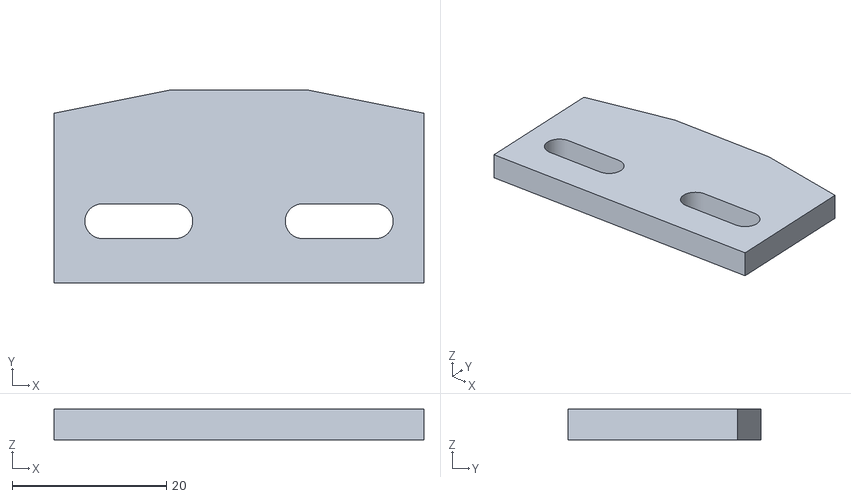
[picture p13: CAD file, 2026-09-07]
cad/phase-1/compact-edge-limits/edge_ramp.stl
48.0 x 25.0 x 4.00

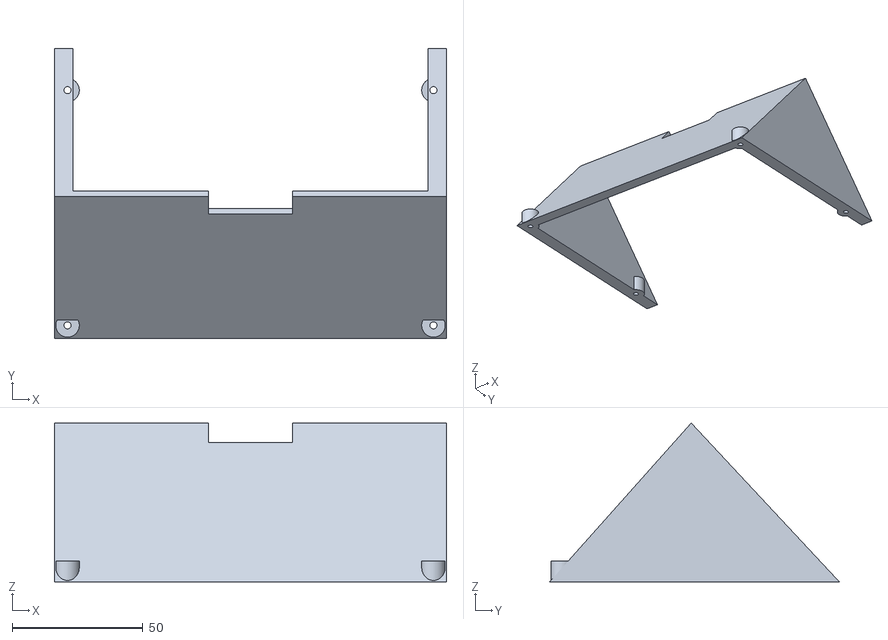
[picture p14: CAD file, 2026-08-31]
cad/phase-1/control-pod/crosswind_alpha_control_pod.stl
150.0 x 111.0 x 60.8

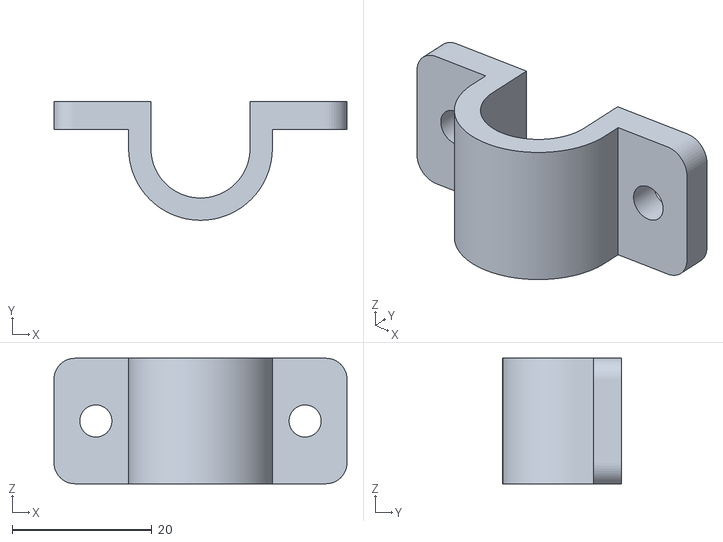
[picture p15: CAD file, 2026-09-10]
cad/phase-1/harness-saddle/Crosswind_Harness_Saddle_13.8mm_PRINT.stl
42.0 x 17.0 x 18.0

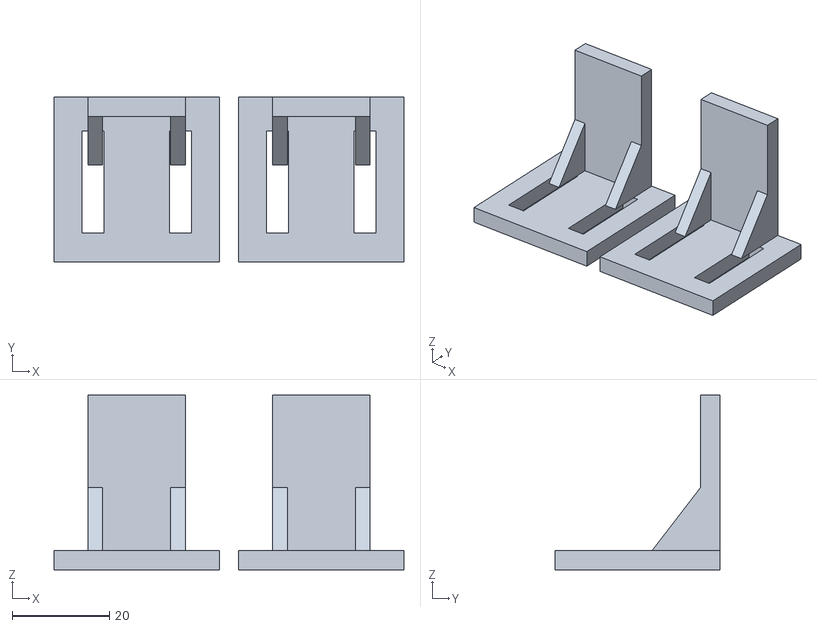
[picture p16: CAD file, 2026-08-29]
cad/phase-1/limit-switch-flag/crosswind_limit_flag_pair.stl
72.0 x 34.0 x 36.0

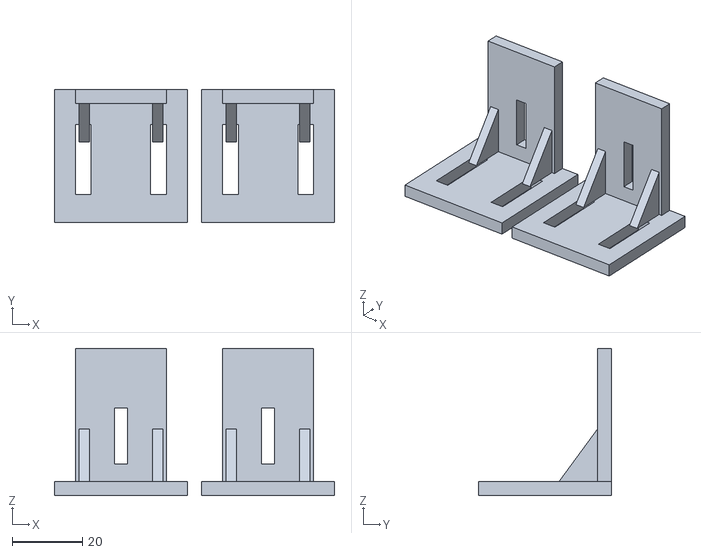
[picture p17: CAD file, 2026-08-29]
cad/phase-1/limit-switch-holder/crosswind_yl99_holder_pair.stl
80.0 x 38.0 x 42.0

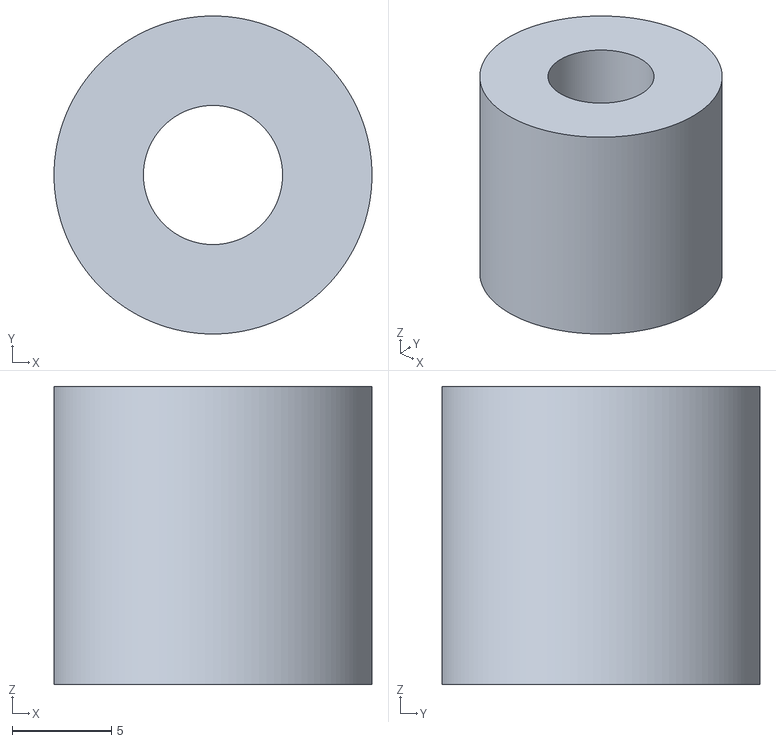
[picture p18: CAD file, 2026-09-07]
cad/phase-1/plate-spacer/Crosswind_Plate_Spacer_15mm_QuarterInch_PRINT.stl
16.0 x 16.0 x 15.0

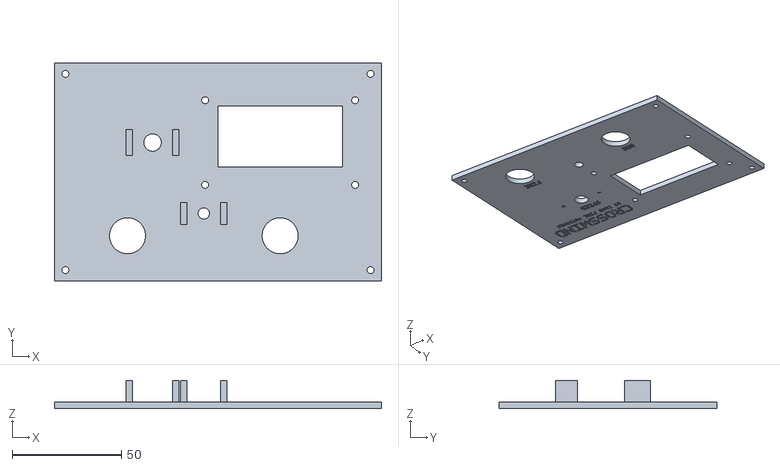
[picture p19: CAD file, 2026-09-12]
cad/phase-1/side-panel/crosswind_alpha_side_panel.stl
150.0 x 100.0 x 13.0

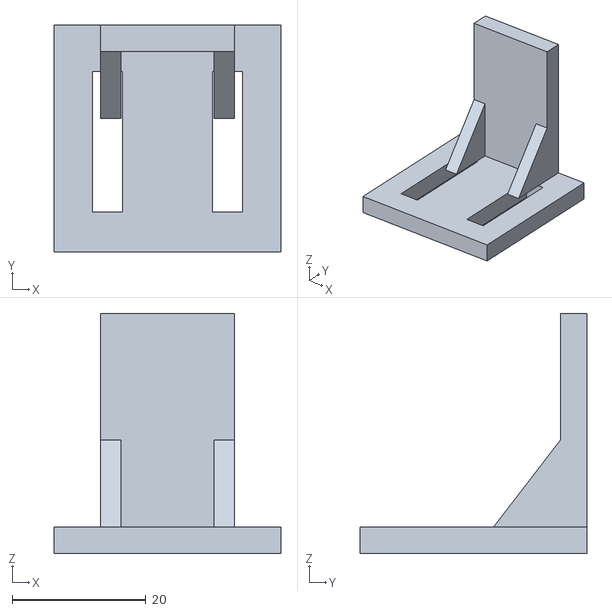
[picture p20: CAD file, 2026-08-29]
cad/phase-1/limit-switch-flag/crosswind_limit_flag.stl
34.0 x 34.0 x 36.0

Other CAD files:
cad/phase-1/limit-switch-holder/crosswind_yl99_holder.stl
cad/phase-1/compact-edge-limits/yl99_edge_bracket.stl
cad/phase-1/controller-connector/PCB_Header_Outer_Relief_All_PRINT.stl
cad/phase-1/controller-connector/PCB_Header_Outer_Relief_2dot_PRINT.stl
cad/phase-1/controller-connector/Connector_Fit_1dot_0.2mm_PRINT.stl
cad/phase-1/controller-connector/Connector_Fit_2dot_0.4mm_PRINT.stl
cad/phase-1/controller-connector/Connector_Fit_3dot_0.6mm_PRINT.stl
cad/phase-1/controller-connector/Connector_Fit_All_Three_PRINT.stl
cad/phase-1/controller-connector/PCB_Header_All_Tests_PRINT.stl
cad/phase-1/controller-connector/PCB_Header_Body_1dot_PRINT.stl
cad/phase-1/controller-connector/PCB_Header_Body_2dot_PRINT.stl
cad/phase-1/controller-connector/PCB_Header_Body_3dot_PRINT.stl
cad/phase-1/controller-connector/PCB_Header_Outer_Relief_1dot_PRINT.stl
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

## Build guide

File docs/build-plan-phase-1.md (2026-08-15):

# Build Plan: Phase 1

## Base Construction

Build a 28" x 28" base from 3/4" plywood. Seal edges if the prototype will be used outdoors. Leave enough edge margin for stake tabs, handles, or tie-down points.

## Top Plate

Cut a 20" x 20" rotating top plate. The thrower rails or temporary fitment blocks mount to this plate.

## Bearing Install

Center a 12" lazy susan bearing between the base and top plate. Mark the centerlines before drilling so the plate rotates squarely.

## VEVOR NH113 Test Fit

Use the VEVOR NH113 as the first fitment target. Keep rails or blocks adjustable instead of drilling a single-purpose pattern into the top plate.

## Wiper Motor Mount

Mount the Mitsubishi Outlander rear wiper motor to the fixed base. The motor should be serviceable and should not interfere with the rotating top plate.

## Linkage

Use a reversing linkage from the motor output to a rear corner or tab on the rotating plate. Confirm by hand that it can move through the complete switch-bounded range without reaching a linkage dead center, binding, or colliding. Start with conservative travel and low PWM before widening the sweep angle.

## Roller Switch Placement

Mount left and right YL-99 roller switch modules on adjustable stationary brackets. Adjustable flags or tabs on the rotating plate should actuate the rollers lightly. The switches command normal firmware reversal but are not load-bearing hard stops; install separate mechanical stops beyond the switch actuation points.

Assemble the limit cable to the [Deutsch DT 6-pin harness standard](../electrical/limit-switch-harness.md). For Alpha, connect Green to Left OUT, Blue to Right OUT, Black to shared ground, and Red to the modules' regulated 3.3 V supply. Terminate White and Yellow in their assigned connector cavities but isolate their equipment-side ends for future use. Verify each OUT reads HIGH normally and LOW when pressed before applying motor power.

## Controller Box

Mount the ESP32, BTS7960, high-current 12V buck, 5V buck, fuse block, and wiring terminals in a waterproof electronics box. Keep the BTS7960 heat sink exposed to airflow and add strain relief for motor, battery, switch, and control wiring.

Use the verified Hosyond 2.42-inch 128x64 SSD1309 OLED for the controller display. Fabricate its lid wiring to the [official five-pin OLED lid-harness standard](../electrical/oled-lid-harness.md), including GPIO5 reset. Preserve the existing 128x64 interface layout. TODO: measure the installed module before revising the enclosure panel opening, mounting-hole locations, standoffs, or display bezel; do not derive mechanical dimensions from the nominal screen size.

Add an opto-isolated trigger relay if thrower launch control is being tested. Keep the factory VEVOR NH113 pedal connected and wire the relay contacts in parallel with the pedal switch.

## First Powered Test

Remove the thrower. Power the ESP32 first, verify Serial diagnostics, verify switch states, then power the motor driver and test low-PWM sweep.

Test trigger output only after confirming the thrower is unloaded, pointed safely, and the black/white pedal wires behave like a simple open/short momentary switch.

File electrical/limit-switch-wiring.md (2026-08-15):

# Limit Switch Wiring

The canonical cable color standard, Deutsch DT 6-pin pinout, connector drawing, wiring diagram, and assembly procedure are in [Limit Switch Harness Standard](limit-switch-harness.md).

Crosswind uses powered YL-99 limit switch modules. Each OUT signal is HIGH normally; pressing the switch shorts OUT to Black ground, producing LOW/active. Red supplies regulated 3.3 V to the modules and Black is their shared ground.

For ESP32 Phase 1:

- Green / Deutsch pin 1 carries the Left limit signal to GPIO34.
- Blue / Deutsch pin 2 carries the Right limit signal to GPIO35.
- Black / Deutsch pin 5 is the shared switch ground.
- Red / Deutsch pin 6 supplies regulated ESP32 3.3 V to the modules.
- White / pin 3 and Yellow / pin 4 are terminated but electrically unused during Alpha.
- GPIO34/GPIO35 are input-only pins without internal pull-ups. The installed powered YL-99 modules provide the required onboard pull-ups; no additional external resistors are installed in Alpha.
- Limit switches command normal end-of-travel reversal and also provide safety input. They must actuate before separate physical hard stops.

Check that normal reads HIGH/clear and pressing either switch reads LOW/active in Serial diagnostics before connecting motor power. Because GPIO34/GPIO35 have no internal pull-ups, a disconnected OUT wire is electrically undefined and is not automatically detected; inspect and continuity-test the harness before operation.

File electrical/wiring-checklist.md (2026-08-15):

# Wiring Checklist

- 20V/24V tool battery positive has a main fuse near the battery.
- High-current buck converter steps the tool battery down to the 12V bus.
- 12V bus feeds BTS7960 motor power and thrower power output through fused branches.
- 12V bus feeds a fused 5V buck for controller/support electronics.
- Motor power is never taken from the 5V buck.
- ESP32 3V3 feeds the OLED, BME280, powered YL-99 modules, and small logic sensors.
- ESP32/Arduino ground and BTS7960 ground are common.
- ESP32 analog input never sees more than 3.3V.
- BTS7960 `RPWM` is wired to GPIO18.
- BTS7960 `LPWM` is wired to GPIO19.
- BTS7960 `R_EN` is wired to GPIO23.
- BTS7960 `L_EN` is wired to GPIO13.
- BME280 `VCC` is wired to ESP32 `3V3`, `GND` to common ground, `SDA` to GPIO21, and `SCL` to GPIO22.
- Serial diagnostics show a recovered/ready BME280 and valid `pressureHpa`.
- Hosyond 2.42-inch SSD1309 OLED `VCC` is wired to ESP32 `3V3` and `GND` to system ground.
- SSD1309 OLED `SDA` is wired to GPIO21 and `SCL` is wired to GPIO22.
- SSD1309 OLED `RES` is wired to GPIO5 for active-LOW hardware reset.
- OLED lid harness uses the official five-position JST connector and the pin order in `oled-lid-harness.md`.
- All five OLED harness conductors pass point-to-point continuity and adjacent-pin short tests.
- OLED starts after a complete cold power cycle without requiring Serial Monitor to reset the ESP32.
- Serial I2C diagnostics report the OLED address, normally `0x3C` (with `0x3D` fallback).
- Rotary encoder `CLK` is wired to GPIO32, `DT` to GPIO33, and `SW` to GPIO25.
- ARM button is wired between GPIO16 and GND.
- FIRE / TEST button is wired between GPIO17 and GND.
- Deutsch DT pin 1 / Green is wired from the Left powered module `OUT` to GPIO34; the module's onboard pull-up provides HIGH/clear.
- Deutsch DT pin 2 / Blue is wired from the Right powered module `OUT` to GPIO35; the module's onboard pull-up provides HIGH/clear.
- Deutsch DT pin 3 / White is terminated for the future Lower / Axis 2 Down limit and remains unused during Alpha.
- Deutsch DT pin 4 / Yellow is terminated for the future Upper / Axis 2 Up limit and remains unused during Alpha.
- Deutsch DT pin 5 / Black is the shared ground for all limit switch modules.
- Deutsch DT pin 6 / Red carries regulated ESP32 3.3 V to all limit switch module `VCC` terminals.
- Molded Deutsch cavity numbers are checked from the mating face before the wedge locks are installed.
- Red-to-Black measures approximately 3.3 V with controller power on.
- Limit switches are confirmed as normal reversal boundaries and safety inputs, with separate mechanical hard stops beyond their actuation points.
- Thrower trigger relay input is wired to GPIO14.
- DIYables RGB LED module `GND` is wired to common ground, `R` to GPIO27, `G` to GPIO12, and `B` to GPIO4.
- GPIO12 is checked for boot/upload issues after wiring the RGB green channel.
- Limit module OUT signals read HIGH normally and LOW/active when pressed.
- Disconnecting an OUT wire leaves GPIO34/GPIO35 undefined; the harness is inspected because open-wire faults are not automatically detected.
- A normal single endpoint reverses motion. Both limits, a switch that fails to release, and travel timeout stop the motor, disarm, block FIRE, and latch a fault.
- Thrower pedal black/white wires are confirmed with a continuity test before relay wiring.
- Trigger relay COM and NO are wired in parallel with the factory pedal, not in series.
- Trigger relay contacts are dry contact only; no ESP32 voltage is sent into the pedal circuit.
- Factory pedal still works with Crosswind powered off.
- Motor wires are secured and strain relieved.
- Enclosure cable glands are tightened.
- A power disconnect is reachable during testing.

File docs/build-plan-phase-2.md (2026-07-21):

# Build Plan: Phase 2

## Tilt Cradle Concept

Add a cradle or subframe that supports the thrower and allows controlled pitch movement. The yaw platform should remain responsible for left/right presentation.

## Linear Actuator Concept

Use a 12V linear actuator or geared mechanism to change thrower pitch. The actuator should have mechanical stops and should not overload the thrower frame.

## Pitch Limit Switches

Add upper and lower pitch limits or a position feedback sensor. The finalized harness reserves White / Deutsch pin 3 for Lower OUT, Yellow / pin 4 for Upper OUT, Black / pin 5 as shared ground, and Red / pin 6 as shared regulated 3.3 V. Match the powered active-LOW modules used for yaw: OUT is HIGH normally and LOW when pressed. The pitch axis should fault independently from yaw if limits disagree or travel timeout occurs.

## ESP32 Control Expansion

The ESP32 firmware should grow from one axis to two coordinated axes. Keep `motor.*` and `modes.*` modular so pitch control can be added without rewriting Phase 1 sweep logic.

## Battery And Power Considerations

Add current budget for the pitch actuator. Consider branch fusing for the thrower, yaw motor, pitch actuator, and 5V electronics supply.

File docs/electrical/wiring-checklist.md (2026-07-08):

# Wiring Checklist

The canonical current wiring checklist lives at:

- `../../electrical/wiring-checklist.md`

That file is kept outside `docs/` with the rest of the wiring package so it stays aligned with pinout and power-system notes.

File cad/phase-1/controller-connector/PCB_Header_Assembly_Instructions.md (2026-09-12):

# Assembled PCB-header fit test

Print PCB_Header_Assembly_All_PRINT.stl: three separate pieces, 44 x 84 mm total.
PETG, 0.4 mm nozzle, 0.2 mm layers, four walls, solid fill, flat as exported,
no supports. Individual Guide, Pin_Plate and Stand STLs are also supplied.
No raised identification dots: all contacting faces are flat.

## Parts and assembly

1. Place the 3 mm tall open rectangular STAND on the table.
2. Rest the 1.2 mm PIN PLATE on it. Its six-hole group goes with the wide header,
   its four-hole group with the narrow header. The stand leaves 3 mm of space
   beneath the plate; 3.19 mm tails through 1.2 mm plastic protrude about 1.99 mm.
3. Place the 2 mm GUIDE on the pin plate, wide opening over the six-hole group.
   Align the short ends, leaving approximately 2 mm of pin plate visible along
   each long edge. Do not glue or clamp these pieces yet.
4. Insert one UNMATED header tails-first through the guide and into the pin
   holes. Slide the guide relative to the pin plate as needed, rather than
   pushing sideways on the pins. The header base rests on the pin plate.
5. Repeat with the other header. If both cannot seat together, test individually
   and report which header needs a different guide position/orientation.
6. Holding the stack and fixed header by hand, gently try the matching cable
   plug. Check full seating, hook engagement and release access. Support the
   header during unplugging; this loose stack does not retain it mechanically.

The guide can slide in both planar directions; there are no alignment pegs or
fasteners to force an unverified offset. Recessed/raised markings are omitted
from this initial stack so neither face is obstructed. If the plate is flipped,
its row offset reverses: use whichever orientation lets the shrouds align, and
report the orientation relative to the hooks. Never bend pins to align the stack.

## Dimensions and scope

Guide openings: six-pin 18 x 7 mm; four-pin 13 x 7 mm (accepted refinement 3-dot).
Pin holes: 1.1 mm square, 2.50 mm provisional pitch (accepted original 2-dot).
The four-pin row is centered at the actual opening center, 32.5 mm from the
left edge. Earlier standalone tail coupons did not establish this registration.

Nominal row placement uses the inferred 3.83 / 2.45 mm body-edge offsets,
allowing for an inferred 6.28 mm body within the accepted 7 mm opening. Because
measurement orientation and size applicability remain uncertain, the guide is
intentionally free to slide. This is a dry mechanical assembly test, not a
finished panel mount or an adapter PCB. Do not solder to the printed pin plate.

Report: do both headers sit square together; do plugs engage/release their hooks;
and how far does the guide need to move from its centered position (a photo is
useful). After this check, the verified registration can be used for the fixed
carrier and adapter board. No power or wiring is needed for this test.

Validation: generator checks each STL is manifold, watertight, consistently
wound, positive-volume and has the expected separate-solid count. Nominal stack
parts have no volume overlap and the measured tail length clears the stand.

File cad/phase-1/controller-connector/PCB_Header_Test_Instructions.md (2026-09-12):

# PCB-header fit tests - 2026-09-12

Print PCB_Header_All_Tests_PRINT.stl for all four pieces (44 x 101 mm footprint).
Individual PCB_Header_Body_1dot_PRINT.stl, PCB_Header_Body_2dot_PRINT.stl,
PCB_Header_Body_3dot_PRINT.stl and PCB_Header_Tails_PRINT.stl are also supplied.
These are new PCB-header tests, distinct from the older cable-housing gauges.

Print flat as exported in PETG, 0.4 mm nozzle, 0.2 mm layers, four walls,
solid fill, no supports. Body plates are 2 mm thick; tail plate is 1.2 mm thick.
Raised dots add 0.6 mm. Remove strings and first-layer burrs before testing.

## Body coupons

Each coupon has a six-pin opening on the left and a four-pin opening on the
right when the raised dots are behind the openings. Insert each UNMATED PCB
header's solder tails first, then check whether its plastic shroud enters the
2 mm plate without force. A body shoulder may stop it; do not force that through.
These rectangular openings check shroud clearance, not retention or hook fit.

The photo-estimated starting envelopes are 18 x 7 mm for six-pin and 13 x 7 mm
for four-pin headers. These are provisional, not caliper measurements.

| Dots | Six-pin opening | Four-pin opening |
| --- | --- | --- |
| 1 | 18.2 x 7.2 mm | 13.2 x 7.2 mm |
| 2 | 18.6 x 7.6 mm | 13.6 x 7.6 mm |
| 3 | 19.0 x 8.0 mm | 14.0 x 8.0 mm |

Start with three dots and work down. Report the smallest comfortable fit for each
header separately. If none fits, report whether the long or short dimension
catches. Do not force or file the connector bodies.

## Tail coupon

The larger 44 x 32 mm plate has two rows, each with six holes on the left and
four on the right. One dot identifies 0.9 mm square holes; two dots identifies
1.1 mm square holes. Both use provisional 2.50 mm pitch. Start with two dots,
insert all tails together, and check whether the normal plastic underside
supports can seat without bending pins. Then try the one-dot row.

The measured pin width is 0.64 mm; its other cross-section dimension remains
unconfirmed. Report which row accepts each header. Loose printed holes cannot
distinguish 2.50 from 2.54 mm pitch or validate a final PCB drill size. This is
a gross fit check, not an electrical adapter board. No wiring or power is needed.

Final support height, PCB footprint, hook access and strain relief remain
separate design steps. The generator checks manifold status, clear cutters,
watertightness, winding, positive volume and the expected separate body count.

## Smaller body refinement - after physical feedback on 2026-09-12

User corrected the original pin-coupon result: TWO-dot row fits (1.1 mm square
printed holes at 2.50 mm provisional pitch); ONE-dot (0.9 mm) was too tight.
This supersedes the initial one-dot report and is not PCB drill qualification.
Original one-dot body openings were closest but still a tad large. The photo
shows both headers; exact looseness by axis was not measured.

Print PCB_Header_Refine_All_PRINT.stl: three body-only coupons, 44 x 64 mm total,
same print settings as above. No need to repeat the tail coupon. A raised BAR at
the other end of the dot edge identifies this refinement series. Keep original
and refinement dot counts distinct. Both axes shrink in 0.2 mm total steps.

| Refinement dots + bar | Six-pin opening | Four-pin opening |
| --- | --- | --- |
| 1 | 17.6 x 6.6 mm | 12.6 x 6.6 mm |
| 2 | 17.8 x 6.8 mm | 12.8 x 6.8 mm |
| 3 | 18.0 x 7.0 mm | 13.0 x 7.0 mm |

Start with THREE dots plus bar (largest), then work down. The largest new opening
is 0.2 mm smaller in width and thickness than the old one-dot. Use unmated PCB
headers, tails first, without forcing. Report best fit for each size separately;
if one axis binds while another remains loose, identify the axis so the next
carrier can use independent width/thickness adjustments. These remain clearance
coupons; the final board support provides retention.

## Four-pin outer-edge relief - 2026-09-12

User selected the refinement three-dot fit (18 x 7 mm six-pin; 13 x 7 mm
four-pin), but reported slight snugness at the four-pin outer side causing it
to sit at a subtle angle. Interpreted outer side as the short edge nearest the
end of the coupon, away from the six-pin opening. This direction is an assumption;
if a long side is the actual interference, report that before adopting the fit.

Print PCB_Header_Outer_Relief_All_PRINT.stl, two coupons in a 44 x 41 mm footprint,
using the same settings. TWO raised bars identify this series. Six-pin openings
remain 18 x 7 mm, with the four-pin inboard edge and 7 mm thickness unchanged.

| Dots + two bars | Four-pin opening | Outboard-edge relief |
| --- | --- | --- |
| 1 | 13.2 x 7.0 mm | 0.2 mm |
| 2 | 13.4 x 7.0 mm | 0.4 mm |

Start with one dot. Try two if it still cants. Check that the unmated header
sits square without force, and report the preferred coupon. Inspect first-layer
burrs before judging. Pin-hole selection remains TWO dots from the original
separate tail coupon (1.1 mm square). These dots identify separate test series.

## Fit clarification: raised identification dots (2026-09-12)

User subsequently attributed the apparent four-pin tilt to the raised coupon
dots preventing the plates from sitting flush together, and believes the fit is
OK. Retain refinement THREE-dot body openings: six-pin 18.0 x 7.0 mm and four-pin
13.0 x 7.0 mm. Retain original TWO-dot tail holes: 1.1 mm square at provisional
2.50 mm pitch. The outer-edge-relief coupons are superseded diagnostic options;
do not carry their enlargement into the carrier. Final mating/support surfaces
must be flat, with identification outside those surfaces. Integrated header
seating and mating still need an assembly fit check.

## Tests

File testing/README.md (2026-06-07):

# Testing

Use this folder to record bench and field test results.

Good logs make it easier to decide whether the next change is firmware, wiring, or mechanical.

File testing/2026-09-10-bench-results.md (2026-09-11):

# Motor bench results and field-test preparation — 2026-09-10

User-reported observations; not independently witnessed. Flashed firmware revision,
PWM, supply voltage, runtime and current measurements were not supplied.

## Bench observations

- Motor system ran and alternated direction when a limit was actuated.
- Physical limit identities appear reversed: the opposite switch produces the
  expected response. Possible ESP32 reassembly wiring mismatch, not yet confirmed.
- Both switches active produces a fault. Holding a limit active produces a fault.
- Throwing operation is already known to work; full mode validation remains open.
- Threaded rod may be backing out of the motor, or flange set screws may be
  slipping on the rod threads. These are separate possible failures.
- Feet still need mounting.
- Logic and voltage plate spacers are printing; installation remains pending.

## Mechanical closeout

### Follow-up: motor direction mismatch identified

User reports display RIGHT produced physical LEFT travel, and vice versa; limit
identities were not the cause. The mechanism reached the opposite endpoint to
the one checked by the travel state, continued driving, and the threaded shaft /
coupling loosened. This supersedes the initial suspected switch-wiring mismatch.
The continued drive plausibly contributed to loosening; independent shaft
retention still needs inspection and testing after direction correction.

Firmware now sets `MOTOR_DIRECTION_INVERTED = true` at the output mapping only.
Logical direction, limit identities, ramping and reversal dead time are retained.
This source change has not been flashed or physically verified. Do not combine
it with a motor-lead swap. Recheck both physical endpoints and starting while on
either limit after installation. The travel routine does not immediately fault
on the opposite limit; this correction does not add that separate protection.

User accepts shared Sweep behavior for Random and Flush in Alpha; distinct
behavior is deferred to Alpha X2 and is not a blocker for scoped Alpha testing.
Verify selection of those modes without claiming distinct motion or auto-throws.

- Mark rod-to-motor and rod-to-flange interfaces separately to identify relative
  movement during an unloaded, low-speed test. Stop if either slips.
- Confirm rod thread diameter/pitch, engagement and the actual rotating motor
  output construction before selecting a jam-nut arrangement or changing length.
- A longer rod and top nut only clamp the flange if there is an opposing solid
  shoulder/nut and a suitable load path. A top nut alone does not establish torque
  retention or stop the rod unscrewing from the motor. Do not clamp against the
  stationary gearbox housing or add unintended bearing preload.
- Medium-strength removable threadlocker such as LOCTITE 243 is a candidate for
  correctly fitted metal threads; follow its preparation and cure instructions.
  Threadlocker on set-screw threads prevents loosening but does not repair poor
  shaft contact or establish the coupling's torque capacity.
- Mount feet; install printed spacers and plates; secure harnesses clear of all
  moving parts. Confirm independent mechanical stops and accessible power cutoff.

## Restore limit identity before powered endpoint testing

1. With motor power disconnected, press the physical left switch: diagnostics
   must show LEFT only; Green / Deutsch 1 must reach GPIO34.
2. Press right: RIGHT only; Blue / Deutsch 2 must reach GPIO35.
3. Correct only an established mismatch. If input identities are correct but
   commanded direction is physically reversed, investigate motor direction mapping
   instead of swapping correctly identified limit signals.
4. With the thrower unloaded, verify low-speed movement toward each endpoint
   reverses away from that same endpoint; starting on either limit moves away.

## Mode verification against saved source

Source: `firmware/crosswind-esp32/src/modes.cpp`, `config.h`, and firmware README.
Saved source is not proof of the revision flashed during this test.

| Mode | Current implementation | Remaining verification |
| --- | --- | --- |
| SWEEP | Bounded travel, stop, reversal dead time, move away, repeat | Both physical endpoints; repeated runs without slippage or normal endpoint faults |
| RANDOM | Same bounded sweep routine as SWEEP; placeholder | Confirm desired distinct behavior before claiming Random feature completion |
| FLUSH | Same bounded sweep routine as SWEEP; placeholder | Confirm desired movement and trigger behavior before claiming Flush feature completion |
| CENTERING | Find endpoint if needed, measure full traverse, return for half measured time, stop | Start mid-travel and at either endpoint; check practical center accuracy at fixed speed |

Centering estimates center by time, not a position sensor. Keep speed unchanged
during its measurement and return. Automatic triggering is documented as disabled
by default; mode selection alone does not establish automatic throw operation.

Saved constants: reversal dead time 50 ms, switch-release timeout 1000 ms,
maximum travel time 30000 ms. The release timeout is a fault threshold, not an
intentional one-second pause at each endpoint. Bench observations support the
fault paths but do not measure their timing.

Before field operation, verify STOP, disarmed FIRE blocking, armed relay pulse,
both-limit fault, stuck-limit fault, travel timeout and intentional fault recovery.
Simulate missing/stuck inputs only in an unloaded setup that cannot drive into a
hard stop. Do not hold a powered mechanism stalled to test a timeout.

Field readiness remains pending shaft retention, corrected direction/limit mapping,
feet and spacer installation, and documented mode/control checks. Initial field
work should begin with unloaded motion before live throwing trials. Random and
Flush remain explicitly unvalidated as distinct modes.

## Thread-retention references

- [Henkel LOCTITE 243 product information](https://next.henkel-adhesives.com/us/en/products/industrial-adhesives/central-pdp.html/loctite-243/BP000000316211.html)
- [Ruland: reasons why collars fail](https://www.ruland.com/media/wysiwyg/PDF/reason-why-collars-fail.pdf)

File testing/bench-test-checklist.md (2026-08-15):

# Bench Test Checklist

## ESP32 Power Test

- Power the ESP32 from the 5V buck converter.
- Open Serial Monitor at 115200.
- Confirm startup diagnostics print.

## Switch Test

- Confirm Red-to-Black measures approximately 3.3 V with controller power on.
- Confirm Green (Left OUT) and Blue (Right OUT) each read HIGH normally and LOW when pressed.
- With power removed, continuity-test Green and Blue end to end. Do not treat a disconnected live input as valid because GPIO34/GPIO35 have no internal pull-ups and will float.
- Trigger the left roller switch and confirm Serial status changes.
- Trigger the right roller switch and confirm Serial status changes.
- Trigger both and confirm a fault is reported.
- Turn the rotary encoder and confirm OLED motor percentage and Serial speed output change.
- Cold-cycle controller power with Serial Monitor closed and confirm the SSD1309 starts through the five-conductor lid harness.
- Press the encoder switch and confirm it opens the menu; verify Motor, Mode, Environment, Diagnostics, and About navigation.
- Press FIRE while OLED shows `SAFE` and confirm Serial prints `FIRE BLOCKED - NOT ARMED`.
- Press ARM and confirm OLED shows `ARMED` and Serial prints `ARM ON`.
- Press FIRE while armed and confirm the relay pulses briefly.
- Press ARM again and confirm OLED returns to `SAFE`.

## Motor Driver Test

- Disconnect the thrower from the rotating plate.
- Verify BTS7960 logic ground and ESP32 ground are common.
- Power the motor branch through a fuse.

## Low PWM Motor Test

- Set speed low.
- Send BLE `START` or use the current bench start mechanism.
- Confirm the wiper motor ramps rather than jerks.

## Sweep Mode No-Load Test

- Let the plate sweep with no thrower mounted.
- Confirm each endpoint stops the current output, observes reversal dead time, moves away, and repeats without a normal endpoint fault.
- Hold a departed switch active beyond `LIMIT_DWELL_MS` and confirm `FAULT_LIMIT`.
- Prevent the next endpoint from activating until `MAX_TRAVEL_TIME_MS` and confirm `FAULT_TRAVEL_TIMEOUT`.
- Activate both limits and confirm `FAULT_BOTH_LIMITS`.
- Run `CENTERING` and confirm a full measured traverse, half-time return, and automatic stop.

## Thrower-Mounted Test

- Mount the thrower only after no-load testing.
- Start at low PWM.
- Watch for tipping, binding, or switch bracket movement.

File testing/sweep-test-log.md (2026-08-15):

# Sweep Test Log

## Alpha v1.12.0-rc.1 Validation

- Date: 2026-08-14
- Firmware version: `Crosswind ESP32 Phase 1 v1.12.0-rc.1`
- Base configuration: Alpha bench mechanism
- Thrower mounted: no
- Sweep reversal: passed at both left and right endpoints
- STOP behavior: passed
- Stuck-limit timeout: passed
- Both-limits fault: passed
- Travel timeout: passed
- Timed centering: passed
- Result: release-candidate motion and limit behavior accepted for mechanical integration

## Test Entry

- Date:
- Firmware version:
- Base configuration:
- Thrower mounted: yes/no
- PWM:
- Sweep time left-to-right:
- Sweep time right-to-left:
- Direction-change dead time:
- Limit-release timeout:
- Travel timeout:
- Limit behavior:
- Faults:
- Mechanical notes:
- Next change:

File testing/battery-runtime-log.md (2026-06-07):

# Battery Runtime Log

## Test Entry

- Date:
- Battery:
- Starting voltage:
- Ending voltage:
- Runtime:
- Thrower branch used: yes/no
- Wobbler branch used: yes/no
- Actuator branch used: yes/no
- Notes:

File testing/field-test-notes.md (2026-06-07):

# Field Test Notes

## Test Entry

- Date:
- Location:
- Ground conditions:
- Thrower:
- Target presentation notes:
- Stability:
- Battery performance:
- Weather:
- Issues:
- Follow-up:

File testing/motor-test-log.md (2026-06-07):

# Motor Test Log

## Test Entry

- Date:
- Motor: Mitsubishi Outlander rear wiper motor
- Wiring notes:
- Supply voltage:
- Fuse size:
- No-load current draw:
- Loaded current draw:
- Startup current:
- Speed setting / PWM:
- Torque impression:
- Heat after test:
- Runtime:
- Issues:
- Next change:

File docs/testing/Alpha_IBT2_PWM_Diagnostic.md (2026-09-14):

# Alpha IBT-2 PWM diagnostic

> Historical diagnostic report. Direction tables/procedures below predate `3563fba`. Current inverted mapping uses logical RIGHT -> LPWM and LEFT -> RPWM. Use the [current firmware guidance](../../firmware/crosswind-esp32/README.md) and verify physical travel before endpoint testing. Historical build results are not current acceptance.

## Bench symptom and root cause

BLE `START` was accepted and the controller entered `RUNNING`. `R_EN` rose to
about 3.2 V, but RPWM and LPWM remained at 0 V and the motor did not move.

The command and ramp path was running. The defect was the final IBT-2 output
truth table in `motor.cpp`: for right motion it set `R_EN` high but forced
`L_EN` low, and for left motion it did the inverse. The BTS7960 module needs
both half-bridge enable inputs high while either PWM input commands motion.
Disabling one half prevented a complete motor-current path.

## Control-flow trace

`BLE write` -> `CommandCallback::onWrite()` -> `handleBleCommand(START)` ->
`state.running = true` -> main `loop()` -> `motorAllowed()` ->
`updateMode()` / bounded mode state machine -> `driveMotor(state.direction, state.speed)`
-> `updateMotorRamp()` -> `writeOutputs()` -> both enables high -> exactly one
of RPWM/LPWM receives the ramped duty.

The default speed is 64 (approximately 25%). With the rotary encoder selected,
`readSpeedPwm()` updates the requested speed each loop; a deliberately selected
speed of zero therefore remains a safe stop request.

## Hardware and PWM mapping

| Signal | ESP32 GPIO | PWM channel (Arduino-ESP32 2.x) |
| --- | ---: | ---: |
| RPWM | 18 | 0 |
| LPWM | 19 | 1 |
| R_EN | 23 | n/a |
| L_EN | 13 | n/a |

PWM is 5 kHz, 8-bit, with raw duty 0-255. Nonzero run requests below 45 are
raised to the configured minimum duty of 45. The normal default is 64
(approximately 25%). The installed build uses Arduino-ESP32 2.0.17, so PWM is
configured with `ledcSetup()`, attached with `ledcAttachPin()`, and written by
channel. The source retains the matching Arduino-ESP32 3.x pin-based API path.
Either setup failure leaves both enables low and all reported duties at zero.

## Safe output behavior

| Commanded state | R_EN | L_EN | RPWM | LPWM |
| --- | ---: | ---: | ---: | ---: |
| Right / forward | HIGH | HIGH | duty | 0 |
| Left / reverse | HIGH | HIGH | 0 | duty |
| Stop, zero speed, inhibit, or PWM init failure | LOW | LOW | 0 | 0 |

RPWM and LPWM are never nonzero together. A direction change first writes both
PWM values to zero and both enables low, waits the configured 50 ms using the
existing nonblocking dead-time state, and then applies the opposite output.
`STOP` immediately clears the request, duties, pending reversal, and enables.

## Diagnostics

Serial reports PWM initialization and the RPWM/LPWM configuration at boot.
BLE `START` logs state, requested speed and direction, fault, and both limit
states. BLE `STOP` is logged. Motor output changes log R_EN, L_EN, RPWM, and
LPWM. The periodic Serial/BLE status includes the motion state, requested
speed/direction, active fault, E-stop, left/right limits, both enable commands,
both PWM duties, and PWM readiness. Output logging is change-driven rather
than emitted on every loop iteration.

## Controlled bench test

The diagnostic option `ENABLE_IBT2_BENCH_TEST` is false by default. It cannot
run automatically. For a supervised test with the linkage unloaded:

1. Verify E-stop and both limits are clear and normal firmware reports
   `pwmReady=1`.
2. Set `ENABLE_IBT2_BENCH_TEST` to `true`, rebuild, and flash.
3. With the normal controller stopped, send `IBT2_BENCH_FORWARD`. The command
   applies duty 64 (about 25%) for one second, then performs a complete stop.
4. Test reverse only as a separate deliberate action by sending
   `IBT2_BENCH_REVERSE`.
5. Send `STOP` at any time to end the test immediately. A fault, E-stop, or
   the limit in the commanded direction also aborts it.
6. Restore the flag to `false` after testing.

A multimeter displays approximately the PWM average: at 3.3 V logic, 25% may
read about 0.8 V, 50% about 1.6 V, and 75% about 2.5 V. Use an oscilloscope or
logic analyzer to confirm frequency and waveform.

## Validation and remaining hardware checks

PlatformIO builds the `esp32dev` environment successfully. GPIO searches show
no duplicate use of GPIO18, GPIO19, GPIO23, or GPIO13, and the two legacy LEDC
channels are distinct. Static output-path review covers forward, reverse,
stop, zero speed, reversal dead time, and PWM setup failure. Runtime safety
gating remains in the main and bounded-mode state machines: E-stop, temperature,
endpoint direction constraints, both-limits/stuck-limit/travel-timeout checks,
session timeout, overcurrent hooks, and fault state all retain authority to stop
motor output.

On the bench, confirm both enable terminals reach about 3.3 V during motion,
only the selected PWM terminal shows a waveform/average, and all four control
terminals return low on `STOP`. If PWM is present but the motor still does not
move, then check IBT-2 logic ground continuity, motor supply at B+/B-, motor
connections at M+/M-, and the module itself. Pin assignments were not changed.

## Files changed

- `firmware/crosswind-esp32/src/config.h`
- `firmware/crosswind-esp32/src/motor.h`
- `firmware/crosswind-esp32/src/motor.cpp`
- `firmware/crosswind-esp32/src/main.cpp`
- `firmware/crosswind-esp32/src/diagnostics.cpp`
- `docs/testing/Alpha_IBT2_PWM_Diagnostic.md`

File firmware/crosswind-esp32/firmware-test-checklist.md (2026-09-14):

# Firmware Test Checklist

Run these checks with the thrower unloaded and the motor linkage disconnected until motor direction and speed are verified.

## Build And Upload

- Run `pio run`.
- Upload with `pio run --target upload`.
- Open the Serial monitor at `115200`.
- Confirm startup diagnostics print firmware version, reset reason, pin/config summary, limit states, fault state, trigger state, and motor PWM.

## Display And Inputs

- Confirm the I2C scan reports every detected address and the SSD1309 OLED boots at configured address `0x3C` or fallback `0x3D`.
- Confirm the five-pin OLED `RES` input is connected to GPIO5 and the display acknowledges after the firmware reset pulse.
- Confirm the complete lid connection follows the official five-conductor JST harness pinout in `../../electrical/oled-lid-harness.md`.
- Cold-cycle power with Serial Monitor closed and confirm the OLED starts without an RTS/DTR reset.
- Confirm full-frame SSD1309 updates remain stable at the configured 100 kHz shared-I2C clock.
- Confirm the I2C scan reports both the SSD1309 and BME280 and runtime display/environment updates continue without a task-watchdog reset.
- If the BME280 is unavailable during startup, confirm it recovers automatically when it begins responding and Serial reports `BME280 recovered on I2C`.
- Confirm the startup screen briefly shows `CROSSWIND`, `Display OK`, and `SSD1309 128x64` before the normal interface.
- If the OLED is unavailable during startup, confirm firmware retries and recovers after the display begins responding without rebooting the controller.
- Confirm OLED home screen shows motor percent, safety state, relay state, and limit status.
- Rotate encoder and confirm speed changes.
- Press the encoder switch to open the root menu, select Motor, and verify Start/Stop and explicit speed editing. Verify direction and Mode changes require stopped motion; visit Environment, Diagnostics and About, then use Back/Exit to return home.
- Press ARM and confirm `SAFE`/`ARMED` toggles when no fault or active limit exists.
- Press FIRE while `SAFE` and confirm relay is blocked.

## Relay

- Confirm relay `COM`/`NO` are dry-contact only with a continuity meter.
- Confirm ESP32 GPIO14 drives only the relay input side.
- While `ARMED`, press FIRE and confirm the relay pulse is non-blocking.
- Confirm repeated FIRE requests inside `MIN_TRIGGER_INTERVAL_MS` are blocked.
- Confirm rapid BLE command writes are rate-limited by `BLE_COMMAND_MIN_INTERVAL_MS`.

## Limits And Faults

- Confirm left YL-99 on GPIO34 reads clear/inactive, then active when triggered.
- Confirm right YL-99 on GPIO35 reads clear/inactive, then active when triggered.
- Confirm START is permitted with one limit active and motion begins only away from that limit; ARM and FIRE remain blocked.
- In `SWEEP`, trigger the limit in the direction of travel and confirm output stops, observes reversal dead time, then moves away without latching a fault.
- Hold the departed limit active longer than `LIMIT_DWELL_MS` and confirm a `LIMIT` fault.
- Prevent either endpoint from activating for `MAX_TRAVEL_TIME_MS` and confirm a `TRAVEL_TIMEOUT` fault.
- In `CENTERING`, confirm one complete end-to-end measurement followed by a half-travel return and automatic stop.
- Trigger both limits together and confirm `BOTH_LIMITS` fault.
- Confirm limit faults cannot clear until both switches are released.
- If `ESTOP_PIN` is configured, trigger it and confirm motor output stops, the system disarms, relay firing is blocked, and the fault cannot clear until released.

## Motor

- Confirm BTS7960 `RPWM`, `LPWM`, `R_EN`, and `L_EN` wiring before motor power.
- Confirm motor PWM changes speed on the bench before connecting linkage.
- Confirm STOP or any fault sets BTS7960 outputs off.
- If motor session timeout is enabled, confirm it faults after `MOTOR_SESSION_TIMEOUT_MS`.
- If motor current sensing is installed and enabled, confirm raw readings are plausible before setting an overcurrent threshold.

## Environment

- Confirm the BME280 is detected at address `0x76` or `0x77` and temperature, humidity, and `pressureHpa` appear in the status payload.
- Confirm temperature fault behavior only after verifying sensor readings are plausible.

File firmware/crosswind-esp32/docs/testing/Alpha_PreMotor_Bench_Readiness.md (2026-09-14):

# CrossWind Alpha Pre-Motor Bench Readiness

> Historical diagnostic report. Direction tables/procedures below predate `3563fba`. Current inverted mapping uses logical RIGHT -> LPWM and LEFT -> RPWM. Use the [current firmware guidance](../../README.md) and verify physical travel before endpoint testing. Historical build results are not current acceptance.

## 1. Original Bench Symptoms

BLE connected and accepted START/STOP. START changed the UI to RUNNING and raised R_EN to about 3.2 V, but RPWM and LPWM both remained at 0 V.

## 2. Root Cause

Repository history shows the original motor output function incorrectly used the IBT-2 enable pins as direction selects: RIGHT asserted only R_EN and LEFT asserted only L_EN. A BTS7960 needs both R_EN and L_EN asserted during either direction; RPWM versus LPWM selects direction. Commit `92c20dd` partially corrected that truth table and added checked LEDC initialization.

This pass closed remaining command-path defects: there was no BLE forward/reverse command, BLE disconnect retained the running command, a stored zero speed could make START silent, and a BLE speed setting was overwritten on the next loop because it was not synchronized to the active input value.

## 3. Pin Map

| Function | GPIO | Mode / notes |
|---|---:|---|
| R_EN | 23 | output |
| L_EN | 13 | output |
| RPWM | 18 | LEDC output |
| LPWM | 19 | LEDC output |
| Left limit | 34 | input-only, active LOW, external/module bias required |
| Right limit | 35 | input-only, active LOW, external/module bias required |
| E-stop | disabled (`-1`) | no Alpha GPIO assigned |

The repository-wide audit found no duplicate GPIO assignments. GPIO34/35 are valid inputs but cannot supply internal pull-ups; firmware now uses `INPUT`. GPIO12 is a boot-strapping pin used by the RGB green input and remains documented; no motor pin is a strapping or input-only pin. BLE uses the ESP32 radio and GATT UUIDs, not control GPIOs.

## 4. PWM Configuration

PlatformIO target is `esp32dev`, platform 7.0.1, Arduino-ESP32 2.0.17. Motor PWM is 5 kHz, 8-bit, range 0-255. With the installed 2.x core, RPWM uses LEDC channel 0 and LPWM channel 1 through `ledcSetup`/`ledcAttachPin`; RGB uses channels 2-4. The guarded 3.x branch uses pin-based `ledcAttach`/`ledcWrite`. Attachment failure disables all motor outputs. Boot calls the motor initializer before other peripherals and commands both PWM outputs and enables low.

## 5. IBT-2 Truth Table

| State | R_EN | L_EN | RPWM | LPWM |
|---|---:|---:|---:|---:|
| STOP / invalid / fault | 0 | 0 | 0 | 0 |
| FORWARD / RIGHT | 1 | 1 | requested duty | 0 |
| REVERSE / LEFT | 1 | 1 | 0 | requested duty |

All four pins are written only by `motor.cpp`. Its bounded output function clears the inactive PWM first and has no state that can assert both PWM duties.

## 6. Default Speed

The Alpha default is defined once as 64/255 (about 25%). Missing, corrupt, or zero stored speed is replaced by this default. START also applies it if state speed is unexpectedly zero. BLE `SPEED=0..255` and the encoder remain configurable and synchronized.

## 7. Direction Logic

Initial direction remains the existing deterministic RIGHT direction. BLE accepts `FORWARD`, `REVERSE`, `DIRECTION=RIGHT`, and `DIRECTION=LEFT`. RIGHT maps to RPWM and LEFT maps to LPWM.

## 8. Reversal Dead-Time

Changing direction while moving immediately commands both PWM outputs and both enables low, enters a nonblocking 50 ms dead-time, then ramps the opposite PWM output. No loop-blocking delay is used.

## 9. Limit-Switch Behavior

Both powered YL-99 outputs are active LOW with 20 ms software debounce. Clear is HIGH and triggered is LOW. GPIO34/35 have no internal pull-ups, so the module output or an external pull-up must provide a defined clear state.

An active RIGHT limit immediately inhibits RIGHT/RPWM and commands a reversal to LEFT after direction-change dead time. An active LEFT limit similarly reverses motion to RIGHT. Both active inhibits either direction and latches a fault. A departed switch must release within `LIMIT_DWELL_MS`, and the next endpoint must be reached within `MAX_TRAVEL_TIME_MS`. The powered limit modules have been verified HIGH when released and LOW when pressed, so `ENABLE_LIMIT_SWITCHES` and `ENABLE_LIMIT_FAULTS` are enabled.

## 10. BLE Start/Stop Behavior

Connect does not move the motor. START selects the current valid direction, guarantees nonzero default duty, and enters the normal ramp. STOP synchronously clears running, pattern state, trigger request, both PWM outputs, and both enables. A later START resumes normally.

## 11. BLE Disconnect Behavior

Disconnect now invokes an immediate safe stop and cancels the trigger before advertising restarts. No nonzero output can remain latched.

## 12. Diagnostic Logging

Event logs cover BLE connection/disconnection, START/STOP, direction/duty changes, output truth-table changes, limit transitions, PWM initialization, reversal state, and disconnect safe stop. The existing once-per-second status payload reports running, direction, requested speed, applied PWM, both enables, both PWM duties, limits, E-stop, and PWM readiness.

## 13. No-Motor Bench Test

Leave M+ and M- disconnected. Confirm B+ to B- is about 12 V, VCC to GND is about 5 V, and ESP32/IBT-2 grounds are common. At STOP verify all four logic outputs are near 0 V. Send START/`FORWARD`: both enables should be about 3.3 V, RPWM measurable, LPWM near 0 V. Send `REVERSE`: observe the zero/dead-time interval, then RPWM near 0 V and LPWM measurable. STOP again.

At 25% duty a multimeter typically averages 3.3 V PWM to about 0.8 V; an oscilloscope or logic analyzer is preferred. With motion commanded toward each limit, trigger it and verify the toward-limit PWM becomes zero; then command the opposite direction and verify movement-away PWM is permitted.

Optional commands `IBT2_BENCH_FORWARD` and `IBT2_BENCH_REVERSE` run a bounded one-second 64/255 output test only when `ENABLE_IBT2_BENCH_TEST` is deliberately enabled. It is disabled by default and never runs at boot.

## 14. Thursday Motor Test Procedure

1. Leave mechanical linkage disconnected.
2. Test new motor directly from fused 12 V briefly.
3. Reverse battery polarity and verify opposite rotation.
4. Record no-load current.
5. Connect motor to IBT-2 M+ / M-.
6. Start at approximately 25% PWM.
7. Test forward.
8. STOP.
9. Test reverse.
10. STOP.
11. Verify limit-switch response.
12. Only then connect the mechanical linkage.
13. Test upper plate unloaded.
14. Gradually increase speed as necessary.
15. Mount/test thrower only after unloaded motion is reliable.

## 15. Files Changed

`src/config.h`, `src/storage.cpp`, `src/inputs.h`, `src/inputs.cpp`, `src/ble_control.h`, `src/ble_control.cpp`, `src/main.cpp`, `src/motor.cpp`, and this document.

## 16. Build/Test Results

PlatformIO `esp32dev` release build: PASS. Arduino-ESP32 2.0.17 used the correct channel-based LEDC API. RAM 41,172/327,680 bytes (12.6%); flash 1,195,589/1,310,720 bytes (91.2%). Repository static search found distinct motor channels 0/1 and RGB channels 2/3/4, no GPIO duplication, and no motor-pin writes outside `motor.cpp`. `git diff --check`: PASS.

## 17. Remaining Hardware Checks

Confirm both limit module OUT pins measure a stable HIGH when clear and LOW when pressed; add external 3.3 V pull-ups if the module cannot guarantee this. Confirm L_EN rises with R_EN, verify real PWM with a scope if available, confirm commanded RIGHT corresponds to desired physical travel, and retain fused motor power. E-stop is not assigned on this Alpha wiring and must not be represented as installed.

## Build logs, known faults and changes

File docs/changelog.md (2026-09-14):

# Changelog

## 2026-09-13 branch consolidation

- Consolidated the complete Alpha history onto main and recorded the disposition of older motion, battery and menu branches under archive tags.
- Established main as the default for routine work and marked historical PWM diagnostics as superseded for output direction.
- Recorded a successful ESP32 release build; no hardware validation was performed. See [consolidation record](branch-consolidation-2026-09-13.md).

## 2026-09-13 repository context

- Added the root working guide, evidence-based status snapshot and engineering decision record.
- Linked the context entry points, refreshed future milestones, and corrected stale motor-direction pinout labels and menu test navigation.
- Recorded unresolved implementation/documentation drift without changing firmware, wiring or geometry.

## v1.12.0-rc.1

- Added hardware-validated left/right endpoint reversal for `SWEEP`, `RANDOM`, and `FLUSH`.
- Added stuck-limit, both-limits, and end-to-end travel timeout protection.
- Added timed `CENTERING`: establish both endpoints, measure full travel, return halfway, and stop.
- Permitted safe startup and motor START from one active endpoint while retaining ARM/FIRE inhibition.
- Verified active-LOW YL-99 modules using their onboard pull-ups and corrected the Deutsch harness polarity wiring.
- Updated the embedded firmware version to `Crosswind ESP32 Phase 1 v1.12.0-rc.1`.

- Alpha hardware revision: promoted the verified Hosyond 2.42-inch SSD1309 OLED to the official display and replaced the former four-conductor OLED lid connection with a five-conductor, five-position JST harness carrying GND, 3.3 V, SDA, SCL, and GPIO5 RESET.
- Refactored ESP32 firmware into PlatformIO-style modules.
- Added Arduino Uno/Nano fallback firmware folder.
- Added Phase 1 mechanical, electrical, testing, branding, and planning documentation.
- Established `SWEEP` as the Phase 1 default mode.

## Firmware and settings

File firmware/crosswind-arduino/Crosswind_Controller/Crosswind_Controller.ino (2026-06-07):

#include <Arduino.h>
#include <EEPROM.h>
#include <avr/wdt.h>

/*
  Iron Pine Outdoors Crosswind - Arduino AVR Phase 1 Prototype Firmware

  Phase 1 hardware:
    Arduino Uno/Nano, BTS7960 / IBT-2 motor driver, 12V Mitsubishi Outlander
    rear wiper motor, left/right roller limit switches, start/stop button,
    mode button, speed potentiometer, 12V battery, and 12V-to-5V buck converter.

  Wiring reference:
    Arduino D5  -> BTS7960 RPWM
    Arduino D6  -> BTS7960 LPWM
    Arduino D7  -> BTS7960 R_EN
    Arduino D8  -> BTS7960 L_EN
    Arduino GND -> BTS7960 GND and battery/buck ground

    Left limit switch  -> D9 and GND, using INPUT_PULLUP
    Right limit switch -> D10 and GND, using INPUT_PULLUP
      Preferred Phase 1 wiring is normally closed. With INPUT_PULLUP this means
      the input is LOW during normal travel and HIGH when the switch opens at
      the limit. Change LIMIT_ACTIVE_STATE if your wiring is different.

    Start/stop button -> D11 and GND, using INPUT_PULLUP
    Mode button       -> D12 and GND, using INPUT_PULLUP
    Speed pot wiper   -> A0, with pot ends to 5V and GND
    Status LED        -> D13 onboard LED

  Future path:
    The mode enum and mode handlers are kept aligned with the ESP32 firmware
    path: SWEEP, RANDOM, FLUSH, CENTERING. Phase 1 uses SWEEP as the reliable
    default. Future modes can grow without changing the basic motor/safety API.
*/

const char* FIRMWARE_VERSION = "Crosswind AVR Phase 1 v1.2";

// Pin assignment for Uno/Nano and BTS7960.
const uint8_t RPWM = 5;
const uint8_t LPWM = 6;
const uint8_t R_EN = 7;
const uint8_t L_EN = 8;
const uint8_t LEFT_LIMIT = 9;
const uint8_t RIGHT_LIMIT = 10;
const uint8_t START_STOP_BUTTON = 11;
const uint8_t MODE_BUTTON = 12;
const uint8_t SPEED_POT = A0;
const uint8_t STATUS_LED = 13;

// Configurable Phase 1 motion and safety constants.
const uint8_t MIN_PWM = 45;
const uint8_t MAX_PWM = 255;
const uint8_t DEFAULT_PWM = 120;
const uint8_t RAMP_STEP = 5;
const uint16_t RAMP_INTERVAL_MS = 20;
const uint16_t LIMIT_DWELL_MS = 1000;
const uint32_t MAX_TRAVEL_TIME_MS = 30000UL;
const uint8_t LIMIT_ACTIVE_STATE = HIGH;

// General AVR controller timing.
const uint16_t DEBOUNCE_DELAY_MS = 50;
const uint16_t DIRECTION_CHANGE_DEADTIME_MS = 50;
const uint32_t BUTTON_STUCK_TIMEOUT_MS = 10000UL;
const uint16_t SERIAL_STATUS_INTERVAL_MS = 1000;
const uint8_t EEPROM_MAGIC = 0xA5;
const uint8_t EEPROM_STATE_VERSION = 2;

enum Direction { DIR_RIGHT, DIR_LEFT };
enum Mode { SWEEP, RANDOM, FLUSH, CENTERING };
enum SweepState { SWEEP_IDLE, SWEEP_MOVING_RIGHT, SWEEP_DWELL_RIGHT, SWEEP_MOVING_LEFT, SWEEP_DWELL_LEFT };
enum FaultCode { FAULT_NONE = 0, FAULT_TRAVEL_TIMEOUT = 1, FAULT_BOTH_LIMITS = 2, FAULT_BUTTON_STUCK = 3, FAULT_STARTUP_BOTH_LIMITS = 4, FAULT_UNKNOWN = 255 };

struct __attribute__((packed)) PersistedState {
  uint8_t magic;
  uint8_t version;
  uint8_t mode;
  uint8_t lastFault;
  uint8_t lastSpeed;
  uint8_t checksum;
};

Mode currentMode = SWEEP;
Direction currentDirection = DIR_RIGHT;
SweepState sweepState = SWEEP_IDLE;
FaultCode lastFaultCode = FAULT_NONE;

bool leftLimitHit = false;
bool rightLimitHit = false;
bool startStopActive = false;
bool faultActive = false;
bool modeButtonEvent = false;

bool lastRawStartPressed = false;
bool lastRawModePressed = false;
bool debouncedStartPressed = false;
bool debouncedModePressed = false;
unsigned long lastStartChange = 0;
unsigned long lastModeChange = 0;
unsigned long startPressBegan = 0;

uint8_t currentPwm = DEFAULT_PWM;
uint8_t requestedMotorPwm = 0;
uint8_t appliedMotorPwm = 0;
Direction requestedDirection = DIR_RIGHT;
Direction activeDirection = DIR_RIGHT;
bool motorRunning = false;
bool directionChangePending = false;
unsigned long directionDeadtimeUntil = 0;
unsigned long lastRampUpdate = 0;

unsigned long motionStartTime = 0;
unsigned long dwellStartTime = 0;
unsigned long lastSerialStatus = 0;

uint8_t calculateEepromChecksum(const PersistedState& state);
void loadPersistentState();
void persistState();
void printStartupDiagnostics();
void printRuntimeStatus();
void readInputs();
void handleModeButton();
void handleSweepMode();
void handleRandomMode();
void handleFlushMode();
void handleCenteringMode();
void beginMotion(Direction dir);
void driveMotor(Direction dir, uint8_t pwm);
void stopMotor();
void updateMotorRamp();
void emergencyStop(FaultCode fault);
void clearFault();
bool bothLimitsActive();
bool travelTimedOut();
const char* modeToString(Mode mode);
const char* directionToString(Direction dir);
const char* faultToString(FaultCode fault);

uint8_t calculateEepromChecksum(const PersistedState& state) {
  return state.magic ^ state.version ^ state.mode ^ state.lastFault ^ state.lastSpeed ^ 0x5A;
}

const char* modeToString(Mode mode) {
  switch (mode) {
    case SWEEP:
      return "SWEEP";
    case RANDOM:
      return "RANDOM";
    case FLUSH:
      return "FLUSH";
    case CENTERING:
      return "CENTERING";
    default:
      return "UNKNOWN";
  }
}

const char* directionToString(Direction dir) {
  return dir == DIR_RIGHT ? "RIGHT" : "LEFT";
}

const char* faultToString(FaultCode fault) {
  switch (fault) {
    case FAULT_NONE:
      return "NONE";
    case FAULT_TRAVEL_TIMEOUT:
      return "TRAVEL_TIMEOUT";
    case FAULT_BOTH_LIMITS:
      return "BOTH_LIMITS";
    case FAULT_BUTTON_STUCK:
      return "BUTTON_STUCK";
    case FAULT_STARTUP_BOTH_LIMITS:
      return "STARTUP_BOTH_LIMITS";
    default:
      return "UNKNOWN";
  }
}

void loadPersistentState() {
  PersistedState state;
  EEPROM.get(0, state);

  bool valid = state.magic == EEPROM_MAGIC &&
               state.version == EEPROM_STATE_VERSION &&
               state.checksum == calculateEepromChecksum(state) &&
               state.mode <= CENTERING &&
               state.lastSpeed <= MAX_PWM;

  if (!valid) {
    currentMode = SWEEP;
    currentPwm = DEFAULT_PWM;
    lastFaultCode = FAULT_NONE;
    persistState();
    return;
  }

  currentMode = (Mode)state.mode;
  currentPwm = state.lastSpeed;
  lastFaultCode = (FaultCode)state.lastFault;
}

void persistState() {
  PersistedState state;
  state.magic = EEPROM_MAGIC;
  state.version = EEPROM_STATE_VERSION;
  state.mode = currentMode;
  state.lastFault = lastFaultCode;
  state.lastSpeed = currentPwm;
  state.checksum = calculateEepromChecksum(state);
  EEPROM.put(0, state);
}

bool bothLimitsActive() {
  return leftLimitHit && rightLimitHit;
}

uint8_t normalizeRunPwm(uint8_t pwm) {
  if (pwm == 0) {
    return 0;
  }
  if (pwm < MIN_PWM) {
    return MIN_PWM;
  }
  if (pwm > MAX_PWM) {
    return MAX_PWM;
  }
  return pwm;
}

void writeMotorOutputs(Direction dir, uint8_t pwm) {
  if (dir == DIR_RIGHT) {
    digitalWrite(L_EN, LOW);
    analogWrite(LPWM, 0);
    digitalWrite(R_EN, HIGH);
    analogWrite(RPWM, pwm);
  } else {
    digitalWrite(R_EN, LOW);
    analogWrite(RPWM, 0);
    digitalWrite(L_EN, HIGH);
    analogWrite(LPWM, pwm);
  }
}

void stopMotor() {
  requestedMotorPwm = 0;
  appliedMotorPwm = 0;
  motorRunning = false;
  directionChangePending = false;
  digitalWrite(R_EN, LOW);
  digitalWrite(L_EN, LOW);
  analogWrite(RPWM, 0);
  analogWrite(LPWM, 0);
}

void driveMotor(Direction dir, uint8_t pwm) {
  if (faultActive) {
    stopMotor();
    return;
  }

  uint8_t normalizedPwm = normalizeRunPwm(pwm);
  if (normalizedPwm == 0) {
    stopMotor();
    return;
  }

  requestedDirection = dir;
  requestedMotorPwm = normalizedPwm;
  currentDirection = dir;

  if (motorRunning && dir != activeDirection && !directionChangePending) {
    analogWrite(RPWM, 0);
    analogWrite(LPWM, 0);
    digitalWrite(R_EN, LOW);
    digitalWrite(L_EN, LOW);
    appliedMotorPwm = 0;
    motorRunning = false;
    directionChangePending = true;
    directionDeadtimeUntil = millis() + DIRECTION_CHANGE_DEADTIME_MS;
  }
}

void updateMotorRamp() {
  if (requestedMotorPwm == 0 || faultActive) {
    return;
  }

  unsigned long now = millis();
  if (directionChangePending) {
    if ((long)(now - directionDeadtimeUntil) < 0) {
      return;
    }
    directionChangePending = false;
  }

  if (now - lastRampUpdate >= RAMP_INTERVAL_MS || appliedMotorPwm == 0) {
    if (appliedMotorPwm < requestedMotorPwm) {
      uint16_t nextPwm = appliedMotorPwm + RAMP_STEP;
      appliedMotorPwm = nextPwm > requestedMotorPwm ? requestedMotorPwm : nextPwm;
    } else if (appliedMotorPwm > requestedMotorPwm) {
      appliedMotorPwm = appliedMotorPwm > RAMP_STEP ? appliedMotorPwm - RAMP_STEP : requestedMotorPwm;
      if (appliedMotorPwm < requestedMotorPwm) {
        appliedMotorPwm = requestedMotorPwm;
      }
    }
    lastRampUpdate = now;
  }

  activeDirection = requestedDirection;
  motorRunning = true;
  writeMotorOutputs(activeDirection, appliedMotorPwm);
}

void emergencyStop(FaultCode fault) {
  stopMotor();
  startStopActive = false;
  if (!faultActive) {
    faultActive = true;
    lastFaultCode = fault;
    persistState();
    Serial.print(F("FAULT: "));
    Serial.println(faultToString(lastFaultCode));
  }
}

void clearFault() {
  stopMotor();
  startStopActive = false;
  faultActive = false;
  lastFaultCode = FAULT_NONE;
  sweepState = SWEEP_IDLE;
  motionStartTime = 0;
  persistState();
  Serial.println(F("Fault cleared"));
}

void readInputs() {
  unsigned long now = millis();

  bool rawStartPressed = digitalRead(START_STOP_BUTTON) == LOW;
  bool rawModePressed = digitalRead(MODE_BUTTON) == LOW;

  if (rawStartPressed != lastRawStartPressed) {
    lastStartChange = now;
    lastRawStartPressed = rawStartPressed;
  }
  if (now - lastStartChange >= DEBOUNCE_DELAY_MS && rawStartPressed != debouncedStartPressed) {
    debouncedStartPressed = rawStartPressed;
    if (debouncedStartPressed) {
      startPressBegan = now;
      if (faultActive && !bothLimitsActive()) {
        clearFault();
      } else if (!faultActive) {
        startStopActive = !startStopActive;
        if (!startStopActive) {
          stopMotor();
          sweepState = SWEEP_IDLE;
        }
      }
    }
  }

  if (debouncedStartPressed && now - startPressBegan >= BUTTON_STUCK_TIMEOUT_MS) {
    emergencyStop(FAULT_BUTTON_STUCK);
  }

  if (rawModePressed != lastRawModePressed) {
    lastModeChange = now;
    lastRawModePressed = rawModePressed;
  }
  if (now - lastModeChange >= DEBOUNCE_DELAY_MS && rawModePressed != debouncedModePressed) {
    debouncedModePressed = rawModePressed;
    if (debouncedModePressed) {
      modeButtonEvent = true;
    }
  }

  leftLimitHit = digitalRead(LEFT_LIMIT) == LIMIT_ACTIVE_STATE;
  rightLimitHit = digitalRead(RIGHT_LIMIT) == LIMIT_ACTIVE_STATE;

  if (bothLimitsActive()) {
    emergencyStop(FAULT_BOTH_LIMITS);
  }

  currentPwm = map(analogRead(SPEED_POT), 0, 1023, 0, MAX_PWM);
}

void handleModeButton() {
  if (!modeButtonEvent) {
    return;
  }

  modeButtonEvent = false;
  if (startStopActive || faultActive) {
    return;
  }

  currentMode = (Mode)((currentMode + 1) % 4);
  sweepState = SWEEP_IDLE;
  stopMotor();
  persistState();

  Serial.print(F("Mode changed: "));
  Serial.println(modeToString(currentMode));
}

void beginMotion(Direction dir) {
  currentDirection = dir;
  motionStartTime = millis();
  driveMotor(dir, currentPwm);
}

bool travelTimedOut() {
  return motionStartTime > 0 && millis() - motionStartTime >= MAX_TRAVEL_TIME_MS;
}

void handleSweepMode() {
  if (!startStopActive || faultActive) {
    stopMotor();
    sweepState = SWEEP_IDLE;
    motionStartTime = 0;
    return;
  }

  unsigned long now = millis();
  switch (sweepState) {
    case SWEEP_IDLE:
      if (rightLimitHit && !leftLimitHit) {
        sweepState = SWEEP_DWELL_RIGHT;
        dwellStartTime = now;
        stopMotor();
      } else if (leftLimitHit && !rightLimitHit) {
        sweepState = SWEEP_DWELL_LEFT;
        dwellStartTime = now;
        stopMotor();
      } else {
        sweepState = currentDirection == DIR_LEFT ? SWEEP_MOVING_LEFT : SWEEP_MOVING_RIGHT;
        beginMotion(currentDirection);
      }
      break;

    case SWEEP_MOVING_RIGHT:
      if (rightLimitHit) {
        stopMotor();
        currentDirection = DIR_LEFT;
        sweepState = SWEEP_DWELL_RIGHT;
        dwellStartTime = now;
        motionStartTime = 0;
        persistState();
      } else if (travelTimedOut()) {
        emergencyStop(FAULT_TRAVEL_TIMEOUT);
      } else {
        driveMotor(DIR_RIGHT, currentPwm);
      }
      break;

    case SWEEP_DWELL_RIGHT:
      stopMotor();
      if (now - dwellStartTime >= LIMIT_DWELL_MS) {
        sweepState = SWEEP_MOVING_LEFT;
        beginMotion(DIR_LEFT);
      }
      break;

    case SWEEP_MOVING_LEFT:
      if (leftLimitHit) {
        stopMotor();
        currentDirection = DIR_RIGHT;
        sweepState = SWEEP_DWELL_LEFT;
        dwellStartTime = now;
        motionStartTime = 0;
        persistState();
      } else if (travelTimedOut()) {
        emergencyStop(FAULT_TRAVEL_TIMEOUT);
      } else {
        driveMotor(DIR_LEFT, currentPwm);
      }
      break;

    case SWEEP_DWELL_LEFT:
      stopMotor();
      if (now - dwellStartTime >= LIMIT_DWELL_MS) {
        sweepState = SWEEP_MOVING_RIGHT;
        beginMotion(DIR_RIGHT);
      }
      break;
  }
}

void handleRandomMode() {
  // Future Crosswind product mode. Phase 1 keeps the same safe sweep behavior.
  handleSweepMode();
}

void handleFlushMode() {
  // Future Crosswind product mode. Phase 1 keeps the same safe sweep behavior.
  handleSweepMode();
}

void handleCenteringMode() {
  // Future Crosswind product mode. Phase 1 keeps the same safe sweep behavior.
  handleSweepMode();
}

void printStartupDiagnostics() {
  Serial.println();
  Serial.println(F("Crosswind AVR startup diagnostics"));
  Serial.print(F("  Firmware: "));
  Serial.println(FIRMWARE_VERSION);
  Serial.print(F("  Mode: "));
  Serial.println(modeToString(currentMode));
  Serial.print(F("  Left limit active: "));
  Serial.println(leftLimitHit ? F("YES") : F("NO"));
  Serial.print(F("  Right limit active: "));
  Serial.println(rightLimitHit ? F("YES") : F("NO"));
  Serial.print(F("  Pot raw: "));
  Serial.println(analogRead(SPEED_POT));
  Serial.print(F("  Current speed PWM: "));
  Serial.println(currentPwm);
  Serial.print(F("  Last EEPROM fault: "));
  Serial.println(faultToString(lastFaultCode));
  Serial.println(F("  Commands: start button toggles run/stop; mode button changes mode only while stopped."));
  Serial.println();
}

void printRuntimeStatus() {
  unsigned long now = millis();
  if (now - lastSerialStatus < SERIAL_STATUS_INTERVAL_MS) {
    return;
  }
  lastSerialStatus = now;

  Serial.print(F("mode="));
  Serial.print(modeToString(currentMode));
  Serial.print(F(" run="));
  Serial.print(startStopActive ? F("1") : F("0"));
  Serial.print(F(" fault="));
  if (faultActive) {
    Serial.print(faultToString(lastFaultCode));
  } else {
    Serial.print(F("NONE"));
  }
  Serial.print(F(" left="));
  Serial.print(leftLimitHit ? F("1") : F("0"));
  Serial.print(F(" right="));
  Serial.print(rightLimitHit ? F("1") : F("0"));
  Serial.print(F(" pot="));
  Serial.print(analogRead(SPEED_POT));
  Serial.print(F(" pwm="));
  Serial.print(currentPwm);
  Serial.print(F(" motorPwm="));
  Serial.print(appliedMotorPwm);
  Serial.print(F(" dir="));
  Serial.println(directionToString(currentDirection));
}

void setup() {
  Serial.begin(9600);
  delay(200);

  uint8_t resetFlags = MCUSR;
  MCUSR = 0;

  pinMode(RPWM, OUTPUT);
  pinMode(LPWM, OUTPUT);
  pinMode(R_EN, OUTPUT);
  pinMode(L_EN, OUTPUT);
  pinMode(LEFT_LIMIT, INPUT_PULLUP);
  pinMode(RIGHT_LIMIT, INPUT_PULLUP);
  pinMode(START_STOP_BUTTON, INPUT_PULLUP);
  pinMode(MODE_BUTTON, INPUT_PULLUP);
  pinMode(SPEED_POT, INPUT);
  pinMode(STATUS_LED, OUTPUT);

  stopMotor();
  loadPersistentState();

  leftLimitHit = digitalRead(LEFT_LIMIT) == LIMIT_ACTIVE_STATE;
  rightLimitHit = digitalRead(RIGHT_LIMIT) == LIMIT_ACTIVE_STATE;
  if (bothLimitsActive()) {
    faultActive = true;
    lastFaultCode = FAULT_STARTUP_BOTH_LIMITS;
    persistState();
  }

  if (resetFlags & _BV(WDRF)) {
    lastFaultCode = FAULT_UNKNOWN;
    persistState();
  }

  randomSeed(analogRead(A1) ^ analogRead(A2) ^ micros());
  printStartupDiagnostics();
  wdt_enable(WDTO_2S);
}

void loop() {
  readInputs();
  handleModeButton();

  switch (currentMode) {
    case SWEEP:
      handleSweepMode();
      break;
    case RANDOM:
      handleRandomMode();
      break;
    case FLUSH:
      handleFlushMode();
      break;
    case CENTERING:
      handleCenteringMode();
      break;
  }

  updateMotorRamp();
  digitalWrite(STATUS_LED, startStopActive && !faultActive ? HIGH : (faultActive ? (millis() / 200) % 2 : LOW));
  printRuntimeStatus();
  wdt_reset();
}

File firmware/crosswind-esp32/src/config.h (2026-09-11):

#ifndef CROSSWIND_CONFIG_H
#define CROSSWIND_CONFIG_H

#include <Arduino.h>

/*
  Crosswind ESP32 Phase 1 configuration

  Wiring summary:
    GPIO18 -> BTS7960 RPWM
    GPIO19 -> BTS7960 LPWM
    GPIO23 -> BTS7960 R_EN
    GPIO13 -> BTS7960 L_EN
    GPIO14 -> opto-isolated relay input for thrower pedal dry contact
    GPIO21 -> OLED SDA
    GPIO22 -> OLED SCL
    GPIO5  -> OLED RES, active LOW
    BME280 -> environment sensor on shared I2C bus, 0x76 or 0x77
    GPIO34 -> left powered limit module OUT (HIGH clear, LOW pressed)
    GPIO35 -> right powered limit module OUT (HIGH clear, LOW pressed)
    GPIO27 -> DIYables RGB LED module R input, PWM
    GPIO12 -> DIYables RGB LED module G input, PWM
    GPIO4  -> DIYables RGB LED module B input, PWM
    GPIO32 -> rotary encoder CLK to GND, INPUT_PULLUP
    GPIO33 -> rotary encoder DT to GND, INPUT_PULLUP
    GPIO25 -> rotary encoder SW to GND, INPUT_PULLUP, menu/select button
    GPIO16 -> ARM button to GND, INPUT_PULLUP
    GPIO17 -> FIRE / TEST button to GND, INPUT_PULLUP
    GPIO39 -> speed potentiometer wiper, 0-3.3V only

  The powered YL-99 limit modules drive OUT HIGH when clear and short OUT to
  GND when pressed, so LIMIT_ACTIVE_STATE must remain LOW. Red in the limit
  harness supplies 3.3 V and Black is common ground. GPIO34/GPIO35 do not have
  internal pull-ups; the powered modules (or external 3.3 V pull-ups) must
  provide a defined HIGH level when clear.

  DIYables common cathode RGB LED module wiring:
    GND -> common ground
    R   -> GPIO27
    G   -> GPIO12
    B   -> GPIO4
  Common cathode means HIGH/PWM > 0 turns a color ON.
  GPIO12 is a strapping pin on many ESP32 boards. GPIO5 is reserved for the
  verified OLED reset circuit and must not be used as an RGB fallback.
*/

const char FIRMWARE_VERSION[] = "Crosswind ESP32 Phase 1 v1.12.0-rc.1";

const int RPWM_PIN = 18;
const int LPWM_PIN = 19;
const int R_EN_PIN = 23;
const int L_EN_PIN = 13;
// Logical LEFT/RIGHT refer to plate travel toward the named limit switches.
// Installed motor was observed moving LEFT on a RIGHT command (2026-09-10).
// Invert the output mapping only; keep limit identities and displayed direction.
const bool MOTOR_DIRECTION_INVERTED = true;
const int LEFT_LIMIT_PIN = 34;
const int RIGHT_LIMIT_PIN = 35;
// The powered limit modules have been verified HIGH when released and LOW when
// pressed. GPIO34/GPIO35 use the modules' onboard pull-ups, not ESP32 pull-ups.
const bool ENABLE_LIMIT_SWITCHES = true;
const bool ENABLE_LIMIT_FAULTS = true;
const bool LIMIT_SWITCHES_USE_INTERNAL_PULLUPS = false;
const int START_STOP_BUTTON_PIN = -1;
const int MODE_BUTTON_PIN = -1;
const int ESTOP_PIN = -1;
const int ARM_BUTTON_PIN = 16;
const int FIRE_BUTTON_PIN = 17;
const int SPEED_POT_PIN = 39;
const int ROTARY_ENCODER_CLK_PIN = 32;
const int ROTARY_ENCODER_DT_PIN = 33;
const int ROTARY_ENCODER_SW_PIN = 25;
const int THROWER_TRIGGER_PIN = 14;
const int RGB_RED_PIN = 27;
// GPIO12 is an ESP32 strapping pin; GPIO5 is reserved for OLED reset.
const int RGB_GREEN_PIN = 12;
const int RGB_BLUE_PIN = 4;
const int OLED_SDA_PIN = 21;
const int OLED_SCL_PIN = 22;
const int OLED_RESET_PIN = 5;
const int MOTOR_CURRENT_SENSE_PIN = -1;

// Future expansion placeholders for Phase 2 and production hardware.
const int PITCH_ACTUATOR_PIN = -1;
const int BATTERY_VOLTAGE_PIN = -1;

const int PWM_CHANNEL_RIGHT = 0;
const int PWM_CHANNEL_LEFT = 1;
const int PWM_FREQ = 5000;
const int PWM_RESOLUTION = 8;
const int RGB_RED_CHANNEL = 2;
const int RGB_GREEN_CHANNEL = 3;
const int RGB_BLUE_CHANNEL = 4;
const int RGB_PWM_FREQ = 1000;
const int RGB_PWM_RESOLUTION = 8;

const uint8_t MIN_PWM = 45;
const uint8_t MAX_PWM = 255;
// Conservative Alpha no-load bench default: 64/255, approximately 25% duty.
const uint8_t DEFAULT_PWM = 64;
const uint8_t RAMP_STEP = 5;
const uint16_t RAMP_INTERVAL_MS = 20;
const uint16_t LIMIT_DWELL_MS = 1000;
const uint32_t MAX_TRAVEL_TIME_MS = 30000UL;
const int LIMIT_ACTIVE_STATE = LOW;

const uint16_t DEBOUNCE_DELAY_MS = 50;
const uint16_t LIMIT_DEBOUNCE_MS = 20;
const uint16_t DIRECTION_CHANGE_DEADTIME_MS = 50;
// Disabled in normal firmware. Enable only for a supervised, unloaded test.
const bool ENABLE_IBT2_BENCH_TEST = false;
const uint8_t IBT2_BENCH_TEST_PWM = 64;
const uint16_t IBT2_BENCH_TEST_DURATION_MS = 1000;
const uint8_t WATCHDOG_TIMEOUT_SECONDS = 5;
const uint16_t BLE_STATUS_INTERVAL_MS = 1000;
const uint16_t BLE_COMMAND_MIN_INTERVAL_MS = 100;
const uint16_t SERIAL_STATUS_INTERVAL_MS = 1000;

enum SpeedInputType { SPEED_INPUT_POTENTIOMETER, SPEED_INPUT_ROTARY_ENCODER };
const SpeedInputType SPEED_INPUT_TYPE = SPEED_INPUT_ROTARY_ENCODER;
const uint8_t ROTARY_ENCODER_SPEED_STEP = 5;

const uint16_t ENV_UPDATE_INTERVAL_MS = 2000;
const float TEMP_WARNING_F = 120.0F;
const float TEMP_FAULT_F = 150.0F;
const bool ENABLE_TEMP_FAULTS = true;
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

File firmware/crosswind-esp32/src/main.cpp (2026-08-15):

#include <Arduino.h>
#include <esp_arduino_version.h>
#include <esp_task_wdt.h>
#include <Wire.h>

#include "ble_control.h"
#include "diagnostics.h"
#include "display.h"
#include "environment.h"
#include "inputs.h"
#include "limits.h"
#include "modes.h"
#include "motor.h"
#include "storage.h"
#include "status_led.h"
#include "trigger.h"

static ControllerState state = {
  SWEEP,
  DIR_RIGHT,
  false,
  false,
  FAULT_NONE,
  DEFAULT_PWM
};

static unsigned long lastBleStatus = 0;
static unsigned long runStartedAt = 0;
static bool systemArmed = false;
static MenuPage menuPage = MENU_CLOSED;
static uint8_t menuSelection = 0;
static bool menuEditing = false;
static bool benchTestActive = false;
static unsigned long benchTestEndsAt = 0;

static void setRunning(bool running);

static uint8_t menuItemCount(MenuPage page) {
  switch (page) {
    case MENU_ROOT: return 6;
    case MENU_MOTOR: return 4;
    case MENU_MODE: return 5;
    case MENU_ENVIRONMENT:
    case MENU_DIAGNOSTICS:
    case MENU_ABOUT: return 1;
    default: return 0;
  }
}

static void openMenuPage(MenuPage page) {
  menuPage = page;
  menuSelection = 0;
  menuEditing = false;
  setEncoderMenuActive(page != MENU_CLOSED);
}

static void closeMenu() {
  bool wasOpen = menuPage != MENU_CLOSED;
  openMenuPage(MENU_CLOSED);
  if (wasOpen) Serial.println("LOCAL MENU EXIT");
}

static void handleBleDisconnect() {
  benchTestActive = false;
  setRunning(false);
  stopMotor();
  cancelThrowerTrigger();
  resetModeState();
  Serial.println("[MOTOR] BLE disconnect safe stop");
}

static void latchFault(FaultCode fault) {
  stopMotor();
  cancelThrowerTrigger();
  systemArmed = false;
  closeMenu();
  setRunning(false);
  state.speed = 0;
  if (state.faultActive) {
    return;
  }
  state.faultActive = true;
  state.lastFault = fault;
  resetModeState();
  saveSettings(state);
  Serial.print("FAULT: ");
  Serial.println(faultToString(fault));
}

static void clearFault() {
  stopMotor();
  cancelThrowerTrigger();
  setRunning(false);
  state.faultActive = false;
  state.lastFault = FAULT_NONE;
  state.speed = readSpeedPwm();
  resetModeState();
  saveSettings(state);
}

static bool limitsReleased() {
  return !leftLimitActive() && !rightLimitActive();
}

static bool directionAllowed(Direction direction) {
  if (bothLimitsActive()) return false;
  if (direction == DIR_LEFT && leftLimitActive()) return false;
  if (direction == DIR_RIGHT && rightLimitActive()) return false;
  return true;
}

static bool movementSafeToStart() {
  return !bothLimitsActive() && !emergencyStopActive();
}

static bool motorAllowed() {
  return state.running && !state.faultActive && !emergencyStopActive();
}

static void setRunning(bool running) {
  if (state.running == running) {
    return;
  }
  state.running = running;
  runStartedAt = running ? millis() : 0;
}

static int readMotorCurrentRaw() {
  if (MOTOR_CURRENT_SENSE_PIN < 0) {
    return -1;
  }
  return analogRead(MOTOR_CURRENT_SENSE_PIN);
}

static bool clearFaultIfSafe(const char* source) {
  if (!state.faultActive) {
    return false;
  }

  if (!limitsReleased() || emergencyStopActive()) {
    Serial.print(source);
    Serial.println(" fault clear blocked: release safety inputs first");
    sendBleResponse("ERROR", "FAULT_CLEAR_BLOCKED_SAFETY_INPUT_ACTIVE");
    return true;
  }

  clearFault();
  Serial.print(source);
  Serial.println(" fault cleared");
  sendBleResponse("OK", "FAULT_CLEARED");
  return true;
}

static bool parseByteValue(const String& value, uint8_t& parsedValue) {
  if (value.length() == 0) {
    return false;
  }

  uint16_t result = 0;
  for (uint16_t i = 0; i < value.length(); i++) {
    char c = value.charAt(i);
    if (c < '0' || c > '9') {
      return false;
    }
    result = result * 10 + (uint16_t)(c - '0');
    if (result > 255) {
      return false;
    }
  }

  parsedValue = (uint8_t)result;
  return true;
}

static void setMode(Mode mode) {
  state.mode = mode;
  setRunning(false);
  cancelThrowerTrigger();
  resetModeState();
  saveSettings(state);
}

static bool triggerAllowed() {
  if (state.faultActive) {
    Serial.println("Trigger ignored: fault active");
    sendBleResponse("ERROR", "TRIGGER_BLOCKED_FAULT");
    return false;
  }

  if (!limitsReleased() || emergencyStopActive()) {
    Serial.println("Trigger ignored: limit active");
    sendBleResponse("ERROR", "TRIGGER_BLOCKED_LIMIT_ACTIVE");
    return false;
  }

  if (!state.running && !ALLOW_TRIGGER_WHEN_STOPPED) {
    Serial.println("Trigger ignored: controller stopped");
    sendBleResponse("ERROR", "TRIGGER_BLOCKED_STOPPED");
    return false;
  }

  return true;
}

static bool requestSafeTrigger() {
  if (!systemArmed) {
    Serial.println("FIRE BLOCKED - NOT ARMED");
    sendBleResponse("ERROR", "FIRE_BLOCKED_NOT_ARMED");
    return false;
  }

  if (!triggerAllowed()) {
    return false;
  }

  bool accepted = requestThrowerTrigger();
  sendBleResponse(accepted ? "OK" : "ERROR", accepted ? "TRIGGER_REQUESTED" : "TRIGGER_BLOCKED_INTERVAL");
  return accepted;
}
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

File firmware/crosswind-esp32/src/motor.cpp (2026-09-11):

#include "motor.h"

#include <esp_arduino_version.h>

static uint8_t requestedPwm = 0;
static uint8_t appliedPwm = 0;
static Direction requestedDirection = DIR_RIGHT;
static Direction activeDirection = DIR_RIGHT;
static bool motorRunning = false;
static bool directionChangePending = false;
static unsigned long directionDeadtimeUntil = 0;
static unsigned long lastRampUpdate = 0;
static bool pwmReady = false;
static uint8_t rightPwmOutput = 0;
static uint8_t leftPwmOutput = 0;
static bool rightEnableOutput = false;
static bool leftEnableOutput = false;

static uint8_t normalizeRunPwm(uint8_t pwm) {
  if (pwm == 0) {
    return 0;
  }
  if (pwm < MIN_PWM) {
    return MIN_PWM;
  }
  return pwm > MAX_PWM ? MAX_PWM : pwm;
}

static void writeRightPwm(uint8_t pwm) {
  rightPwmOutput = pwmReady ? pwm : 0;
#if ESP_ARDUINO_VERSION_MAJOR >= 3
  if (pwmReady) ledcWrite(RPWM_PIN, pwm);
#else
  if (pwmReady) ledcWrite(PWM_CHANNEL_RIGHT, pwm);
#endif
}

static void writeLeftPwm(uint8_t pwm) {
  leftPwmOutput = pwmReady ? pwm : 0;
#if ESP_ARDUINO_VERSION_MAJOR >= 3
  if (pwmReady) ledcWrite(LPWM_PIN, pwm);
#else
  if (pwmReady) ledcWrite(PWM_CHANNEL_LEFT, pwm);
#endif
}

static void writeOptionalPin(int pin, uint8_t value) {
  if (pin >= 0) {
    digitalWrite(pin, value);
  }
}

static void writeOutputs(Direction dir, uint8_t pwm) {
  // The BTS7960 uses one enable input per half-bridge. Both halves must be
  // enabled to provide a complete current path; RPWM/LPWM select direction.
  if (!pwmReady || pwm == 0) {
    writeRightPwm(0);
    writeLeftPwm(0);
    writeOptionalPin(R_EN_PIN, LOW);
    writeOptionalPin(L_EN_PIN, LOW);
    rightEnableOutput = false;
    leftEnableOutput = false;
    return;
  }
  writeOptionalPin(R_EN_PIN, HIGH);
  writeOptionalPin(L_EN_PIN, HIGH);
  rightEnableOutput = R_EN_PIN >= 0;
  leftEnableOutput = L_EN_PIN >= 0;

  const bool useRightPwm = (dir == DIR_RIGHT) != MOTOR_DIRECTION_INVERTED;
  if (useRightPwm) {
    writeLeftPwm(0);
    writeRightPwm(pwm);
  } else {
    writeRightPwm(0);
    writeLeftPwm(pwm);
  }
}

static void writeEnables(bool enabled) {
  rightEnableOutput = enabled && R_EN_PIN >= 0;
  leftEnableOutput = enabled && L_EN_PIN >= 0;
  writeOptionalPin(R_EN_PIN, enabled ? HIGH : LOW);
  writeOptionalPin(L_EN_PIN, enabled ? HIGH : LOW);
}

static void logOutputsIfChanged() {
  static bool first = true;
  static uint8_t lastRightPwm = 0, lastLeftPwm = 0;
  static bool lastRightEnable = false, lastLeftEnable = false;
  if (!first && lastRightPwm == rightPwmOutput && lastLeftPwm == leftPwmOutput &&
      lastRightEnable == rightEnableOutput && lastLeftEnable == leftEnableOutput) return;
  first = false;
  lastRightPwm = rightPwmOutput;
  lastLeftPwm = leftPwmOutput;
  lastRightEnable = rightEnableOutput;
  lastLeftEnable = leftEnableOutput;
  Serial.printf("MOTOR OUT R_EN=%u L_EN=%u RPWM=%u LPWM=%u\n",
                rightEnableOutput, leftEnableOutput, rightPwmOutput, leftPwmOutput);
}

bool beginMotor() {
  pinMode(RPWM_PIN, OUTPUT);
  pinMode(LPWM_PIN, OUTPUT);
  if (R_EN_PIN >= 0) {
    pinMode(R_EN_PIN, OUTPUT);
  }
  if (L_EN_PIN >= 0) {
    pinMode(L_EN_PIN, OUTPUT);
  }

#if ESP_ARDUINO_VERSION_MAJOR >= 3
  bool rightAttached = ledcAttach(RPWM_PIN, PWM_FREQ, PWM_RESOLUTION);
  bool leftAttached = ledcAttach(LPWM_PIN, PWM_FREQ, PWM_RESOLUTION);
  pwmReady = rightAttached && leftAttached;
#else
  bool rightAttached = ledcSetup(PWM_CHANNEL_RIGHT, PWM_FREQ, PWM_RESOLUTION) > 0;
  bool leftAttached = ledcSetup(PWM_CHANNEL_LEFT, PWM_FREQ, PWM_RESOLUTION) > 0;
  ledcAttachPin(RPWM_PIN, PWM_CHANNEL_RIGHT);
  ledcAttachPin(LPWM_PIN, PWM_CHANNEL_LEFT);
  pwmReady = rightAttached && leftAttached;
#endif

  stopMotor();
  Serial.printf("MOTOR PWM init %s: RPWM=%d LPWM=%d freq=%dHz resolution=%dbit\n",
                pwmReady ? "OK" : "FAILED", RPWM_PIN, LPWM_PIN, PWM_FREQ, PWM_RESOLUTION);
  Serial.printf("MOTOR direction mapping: inverted=%s (logical plate LEFT/RIGHT)\n",
                MOTOR_DIRECTION_INVERTED ? "YES" : "NO");
  return pwmReady;
}

void stopMotor() {
  requestedPwm = 0;
  appliedPwm = 0;
  motorRunning = false;
  directionChangePending = false;
  writeRightPwm(0);
  writeLeftPwm(0);
  writeEnables(false);
  logOutputsIfChanged();
}

void driveMotor(Direction dir, uint8_t pwm) {
  if (!pwmReady) {
    stopMotor();
    return;
  }
  if (dir != DIR_RIGHT && dir != DIR_LEFT) {
    Serial.println("MOTOR command rejected: invalid/conflicting direction");
    stopMotor();
    return;
  }
  uint8_t normalizedPwm = normalizeRunPwm(pwm);
  if (normalizedPwm == 0) {
    stopMotor();
    return;
  }

  bool commandChanged = requestedDirection != dir || requestedPwm != normalizedPwm;
  requestedDirection = dir;
  requestedPwm = normalizedPwm;

  if (motorRunning && dir != activeDirection && !directionChangePending) {
    writeRightPwm(0);
    writeLeftPwm(0);
    writeEnables(false);
    appliedPwm = 0;
    motorRunning = false;
    directionChangePending = true;
    directionDeadtimeUntil = millis() + DIRECTION_CHANGE_DEADTIME_MS;
    logOutputsIfChanged();
  }

  if (commandChanged) {
    Serial.printf("[MOTOR] direction=%s requestedDuty=%u/255 reversal=%s\n",
                  dir == DIR_RIGHT ? "RIGHT" : "LEFT", normalizedPwm,
                  directionChangePending ? "DEAD_TIME" : "NONE");
  }
}
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

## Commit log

2026-05-25 Apply feature and hardening updates to CrossWind AVR and ESP32 sketches, and update README
2026-05-26 Add AVR EEPROM checksum validation and ESP32 BLE/preferences hardening
2026-05-27 Add motor stall timeout protection across AVR and ESP32 controllers
2026-05-31 Enable hardware watchdog resets for AVR and ESP32 sketches
2026-05-31 CI: add compile workflow; ESP32: persist BLE auth token and SETAUTH
2026-05-31 AVR: add stall recovery retries, retry counters, and recovery logs
2026-05-31 AVR: move enum declarations above functions to satisfy Arduino prototype generator
2026-05-31 AVR: add safe-default restore, reset-cause persistence, mode persistence, and fault LED hardening
2026-05-31 chore: ignore generated Arduino CLI bin directory and persist sketch hardening changes
2026-06-07 Refactor Crosswind repo for Phase 1 prototype
2026-07-01 Add ESP32 environment display support
2026-07-01 Update Alpha ESP32 controls and wiring docs
2026-07-07 Add Alpha ESP32 RGB status LED support
2026-07-07 Add BME280 environment sensor support
2026-07-07 Add Alpha limit switch safety faults
2026-07-08 Harden Alpha ESP32 safety controls
2026-07-08 Sync docs with Alpha ESP32 firmware
2026-07-09 Harden firmware diagnostics and motor gating
2026-07-15 Add optional motor fault hooks
2026-07-15 Add ESP32 PlatformIO CI build
2026-07-19 Replace DHT with BME280 environment sensor
    [config.h, diagnostics.cpp, environment.cpp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]
2026-07-21 Document finalized limit switch harness
2026-07-21 Prevent I2C startup watchdog reset
    [display.cpp, environment.cpp]
2026-07-21 Skip unavailable OLED during startup
    [display.cpp]
2026-07-21 Align limit harness with powered switches
2026-07-22 Probe both common OLED addresses
2026-07-22 Add SSD1309 hardware reset
    [display.cpp]
2026-07-22 Restore shared I2C bus after OLED init
2026-07-23 Avoid restarting active I2C bus
    [main.cpp]
2026-07-23 Stabilize SSD1309 I2C transfers
    [display.cpp]
2026-07-23 Reverse rotary encoder speed direction
    [inputs.cpp]
2026-07-23 Delay OLED reset on cold power-up
    [display.cpp]
2026-07-24 Standardize five-pin OLED lid harness
2026-08-04 Fix IBT-2 PWM motor control
    [config.h, diagnostics.cpp, main.cpp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]
2026-08-06 Add encoder local motor control menu
2026-08-14 Disable floating limit inputs during motor tests
2026-08-14 Enable verified limit switch protection
2026-08-29 Add printable YL-99 limit switch holders
    [crosswind_yl99_holder.stl, crosswind_yl99_holder_pair.stl]
2026-08-29 Resize limit switch holders to measured module
    [crosswind_yl99_holder.stl, crosswind_yl99_holder_pair.stl]
2026-08-29 Add printable limit switch striker flags
    [crosswind_limit_flag.stl, crosswind_limit_flag_pair.stl]
2026-08-29 Add printable Alpha side panel
    [crosswind_alpha_side_panel.stl]
2026-08-29 Engrave Trailboss face plate branding
    [crosswind_alpha_side_panel.stl]
2026-08-29 Correct Crosswind face plate branding
    [crosswind_alpha_side_panel.stl]
2026-08-29 Refine Alpha side panel controls
    [crosswind_alpha_side_panel.stl]
2026-08-30 Add control panel anti-rotation stops
    [crosswind_alpha_side_panel.stl]
2026-08-30 Label control panel speed encoder
    [crosswind_alpha_side_panel.stl]
2026-08-30 Orient control panel for flat printing
    [crosswind_alpha_side_panel.stl]
2026-08-30 Lower control panel LED module
    [crosswind_alpha_side_panel.stl]
2026-08-30 Enlarge control panel encoder opening
    [crosswind_alpha_side_panel.stl]
2026-08-30 Add angled control pod and base feet
    [crosswind_alpha_base_foot.stl, crosswind_alpha_control_pod.stl]
2026-08-30 Mirror control panel for face-down printing
    [crosswind_alpha_side_panel.stl]
2026-08-30 Raise control module anti-rotation rails
    [crosswind_alpha_side_panel.stl]
2026-08-30 Add control pod M3 receivers
    [crosswind_alpha_control_pod.stl]
2026-08-30 Eliminate control pod cantilevers
    [crosswind_alpha_control_pod.stl]
2026-08-30 Remove control pod floating screw arches
    [crosswind_alpha_control_pod.stl]
2026-08-30 Remove all control pod floating facets
    [crosswind_alpha_control_pod.stl]
2026-08-31 Fit control pod flush to wooden side
    [crosswind_alpha_control_pod.stl]
2026-09-07 Add compact YL-99 edge bracket and ramp prototype STL kit
    [complete_two_endpoint_kit.stl, edge_ramp.stl, yl99_edge_bracket.stl]
2026-09-07 Add 15 mm hollow plate spacer for quarter-inch mounting bolts
    [Crosswind_Plate_Spacer_15mm_QuarterInch_PRINT.stl]
2026-09-10 Add printable saddle for 13.8 mm harness loom
    [Crosswind_Harness_Saddle_13.8mm_PRINT.stl]
2026-09-11 Record motor bench results and remaining field readiness checks
2026-09-11 Correct installed motor direction at PWM output mapping
    [config.h, motor.cpp]
2026-09-11 Record measured controller connectors and add clearance fit prints
    [Connector_Fit_1dot_0.2mm_PRINT.stl, Connector_Fit_2dot_0.4mm_PRINT.stl, Connector_Fit_3dot_0.6mm_PRINT.stl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]
2026-09-11 Add measured rib clearance to connector fit gauges
    [Connector_Fit_1dot_0.2mm_PRINT.stl, Connector_Fit_2dot_0.4mm_PRINT.stl, Connector_Fit_3dot_0.6mm_PRINT.stl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]
2026-09-12 Widen connector gauge reliefs for measured hooked ribs
    [Connector_Fit_1dot_0.2mm_PRINT.stl, Connector_Fit_2dot_0.4mm_PRINT.stl, Connector_Fit_3dot_0.6mm_PRINT.stl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]
2026-09-12 Record confirmed six and four pin connector fits
2026-09-12 Define IPC101 panel connector and Alpha migration plan
2026-09-12 Select confirmed hook-retained PCB headers for panel connector
2026-09-12 Record header pin gap and width measurements
2026-09-12 Record full-row connector pitch measurement
2026-09-12 Add PCB header body and solder-tail fit test prints
    [PCB_Header_All_Tests_PRINT.stl, PCB_Header_Body_1dot_PRINT.stl, PCB_Header_Body_2dot_PRINT.stl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]
2026-09-12 Refine header body fit coupons and record accepted tail fit
    [PCB_Header_Refine_1dot_PRINT.stl, PCB_Header_Refine_2dot_PRINT.stl, PCB_Header_Refine_3dot_PRINT.stl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]
2026-09-12 Correct accepted header tail fit to two-dot holes
2026-09-12 Relieve four-pin header outer edge in fit coupons
    [PCB_Header_Outer_Relief_1dot_PRINT.stl, PCB_Header_Outer_Relief_2dot_PRINT.stl, PCB_Header_Outer_Relief_All_PRINT.stl]
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2026-09-12 Record header pin-row edge offsets for assembly prototype
2026-09-12 Add adjustable assembled PCB header fit prototype
    [PCB_Header_Assembly_All_PRINT.stl, PCB_Header_Assembly_Guide_PRINT.stl, PCB_Header_Assembly_Pin_Plate_PRINT.stl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]
2026-09-12 Move OLED faceplate window upward 2.75 mm
    [crosswind_alpha_side_panel.stl]
